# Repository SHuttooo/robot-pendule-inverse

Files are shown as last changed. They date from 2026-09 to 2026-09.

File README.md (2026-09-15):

# Robot pendule inversé

*Inverted pendulum robot. The name stays in French: this project was made in France.*

**English** · [Français](README.fr.md)

**A two-wheel robot that balances on its own: first with a hand-tuned dual PID,
then with a neural network trained in simulation and running on the ESP32.**

<table>
<tr>
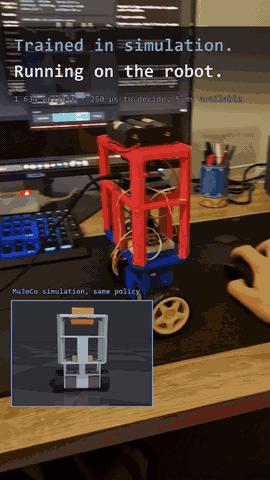
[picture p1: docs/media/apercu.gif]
The real robot pushed by hand, simulation in the corner
<td></td>
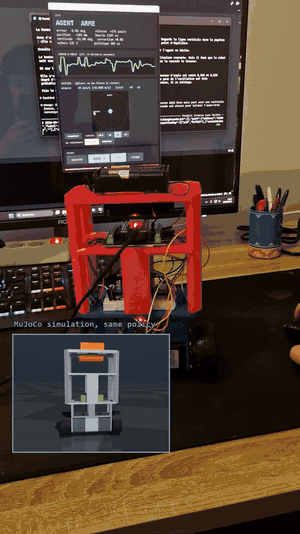
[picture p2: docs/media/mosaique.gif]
The 16 training checkpoints in simulation
<td></td>
</tr>
<tr>
<td align="center">real robot, same policy as in simulation</td>
<td align="center">16 training checkpoints, 9 M steps</td>
</tr>
</table>

Full video (45 s): see the [latest release](../../releases/latest).

> The code, its comments and the detailed documentation in the subfolders are
> in French. This page is the English entry point.

---

## Two ways to control the robot

The same firmware contains both, and you can switch between them live
(serial command `1` or `2`, or a button on the control panel).

| | **dual PID** (`1`) | **learned policy** (`2`) |
|---|---|---|
| origin | tuned by hand, to put my control engineering courses into practice | trained with PPO in MuJoCo |
| structure | 200 Hz angle loop → wheel acceleration, 40 Hz position loop that shifts the target angle, auto-trim of the upright angle | a 15 → 32 → 32 → 2 network, 1,634 weights, replacing both loops and deciding at 100 Hz |
| shared | IMU reading, speed integration, step generation, safety checks | same |

**In practice:** arm the dual PID for one minute first. Its auto-trim finds the
true upright angle, which the policy then reuses. The policy has no auto-trim.

The dual PID is also the **reference**: in simulation (`simulation/firmware.py`,
`08_agent.py --duel`) as on the robot, it tells whether a bad result comes from
the policy or from the hardware. On 9 September, run before the policy, it
balanced twelve times worse than earlier that evening: the problem was the
robot (discharged batteries: once recharged, everything worked again), not the
retraining.

---

## What's inside

```
hardware/     mechanics: SolidWorks CAD, STL, bill of materials, wiring, actual assembly
firmware/     ESP32 code: dual PID, learned policy, safety checks, serial commands
tools/        serial monitor (timestamped log) and control panel with joystick
simulation/   MuJoCo, Gymnasium environment, PPO, C export, videos
docs/         tuning notebook (as of 28 August), project log (pitfalls, decisions, results)
donnees/      raw serial logs from the robot, source of every measured number
```

| | |
|---|---|
| [`hardware/README.md`](hardware/README.md) | parts, assembly, **differences from the CAD** (IMU moved) |
| [`hardware/wiring.md`](hardware/wiring.md) | ESP32, A4988, MPU-6050 pinout, power supply |
| [`firmware/README.md`](firmware/README.md) | real-time architecture, commands, telemetry, flashing |
| [`simulation/README.md`](simulation/README.md) | the model, training, export to the ESP32 |
| [`simulation/modeles/balancier.xml`](simulation/modeles/balancier.xml) | **the robot model**, in MJCF (MuJoCo's XML format) |
| [`docs/journal/PIEGES.md`](docs/journal/PIEGES.md) | bugs met along the way, what they cost, the rule learned |
| [`docs/journal/RESULTATS.md`](docs/journal/RESULTATS.md) | every number, with the command that produces it |

---

## Results

**The simulation matches the real robot.** The same policy, evaluated in
simulation and on the hardware:

| | simulation | real robot |
|---|---|---|
| tilt error, standard deviation | 1.743° | 1.572° |
| motor command, standard deviation | 873 steps/s | 878 steps/s |

1% difference on the command, about 10% on the tilt. The simulation was never
fitted to this observation: only the motor resonance and the sensor noise were
calibrated, each measured separately.

**Retrained on this faithful model**, the new policy, in simulation:

| | old policy | **new policy** | dual PID |
|---|---|---|---|
| tilt error, standard deviation | 1.743° | **0.106°** | 0.185° |
| command, standard deviation | 873 steps/s | **47 steps/s** | 86 steps/s |
| position drift | 55 mm | 12 mm | 13 mm |
| survival at maximum difficulty | 25% | **42%** | 33% |

On the robot, the new policy balanced for 76 s with a command standard
deviation of 536 steps/s, versus 893 for the old one. **A measured comparison
against the dual PID on the hardware is still to be done.**

The hand-tuned dual PID had first brought the tilt error down from 0.293° to
0.064° (see the [notebook](docs/carnet-du-balancier.html), in French). Its purpose
was to put my control engineering courses into practice, not to build the best
possible controller.

**I deliberately skipped the full control engineering approach**: modelling the
pendulum, deriving its transfer function, finding its poles and designing a
controller properly. The gains were found by trial and measurement on the
robot, and I then moved straight on to reinforcement learning, which was the
real goal of the project.

---

## Getting started

**Simulation** (Python 3.12, from `simulation/`):

```
pip install -r requirements.txt
pip install torch --index-url https://download.pytorch.org/whl/cpu

python modele.py --etat                 every parameter and where it comes from
python 01_regarder.py                   the robot in the viewer
python 08_agent.py --agent agents/balancier_final.zip
python 08_agent.py --duel               policy against dual PID
python 07_ppo.py --actionneur couple --pas 9000000       retrain (~16 min)
python 11_export_c.py --agent agents/balancier_final.zip
python 12_valider_c.py                  the C code must match PyTorch
```

**Firmware**: open `firmware/robot_balancier/robot_balancier.ino` in the
Arduino IDE, board *ESP32 Dev Module*, esp32 core 3.3.

**Driving the robot** (Windows):

```
powershell -ExecutionPolicy Bypass -File tools\serial_monitor.ps1
python tools\pupitre.py
```

---

## Timeline

| | |
|---|---|
| **August 2026** | frame, electronics, dual PID tuned by hand through trial and measurement, without a full model. A quick calculation shows that commanding wheel speed cannot stabilise an inverted pendulum: switch to commanding acceleration. A bug in Espressif's I2C driver tracked down with `addr2line`. |
| **5 Sept** | MuJoCo model rebuilt from the SolidWorks assembly, firmware ported to simulation as a reference, first PPO policy. |
| **9 Sept** | policy exported to C and validated against PyTorch. Board crashes fixed by moving I2C to a dedicated task. Motor identified in closed loop with frequency sweeps and cross-spectra, without taking the robot apart: resonance at 71 Hz, not 113. Retraining on the faithful motor model. |
| **10 Sept** | steering (two independent wheel speeds from a single timer), joystick control panel, video. |

## Still open

- measure the dual PID and the policy on the hardware, under the same conditions;
- set the A4988 Vref, never measured;
- the period of the robot hanging as a pendulum, an independent check of the model ([`docs/MESURES.md`](docs/MESURES.md)).

---

**Matthieu Vinet**, robotics engineering student at Polytech Sorbonne ·
[matthieu-vinet.fr](https://matthieu-vinet.fr/)

Code written with Claude Code as a programming assistant. [MIT](LICENSE) license.

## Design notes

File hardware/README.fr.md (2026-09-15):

# Mécanique et matériel

[English](README.md) · **Français**

<table>
<tr>
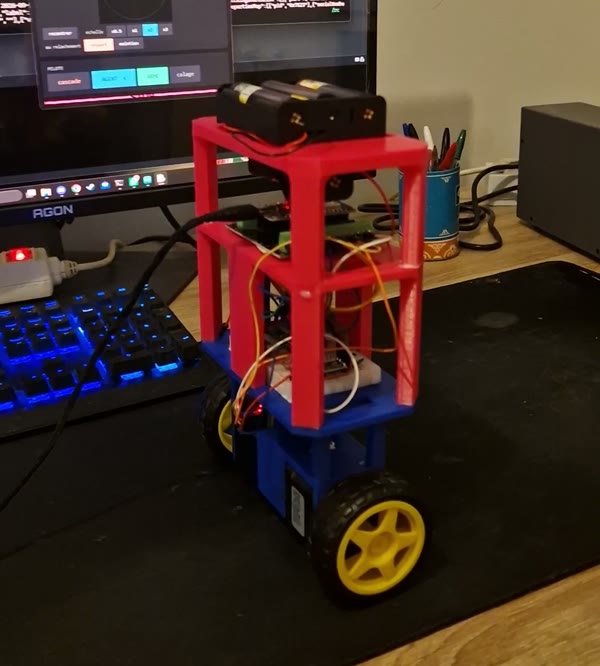
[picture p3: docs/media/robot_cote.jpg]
Le robot de côté
<td></td>
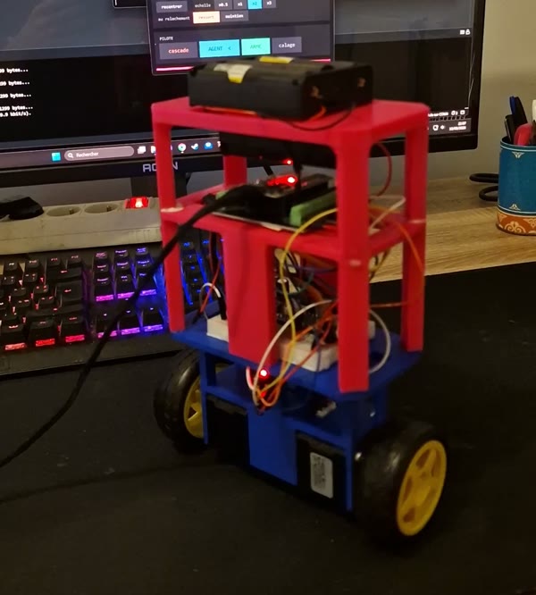
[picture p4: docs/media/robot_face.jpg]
Le robot de face
<td></td>
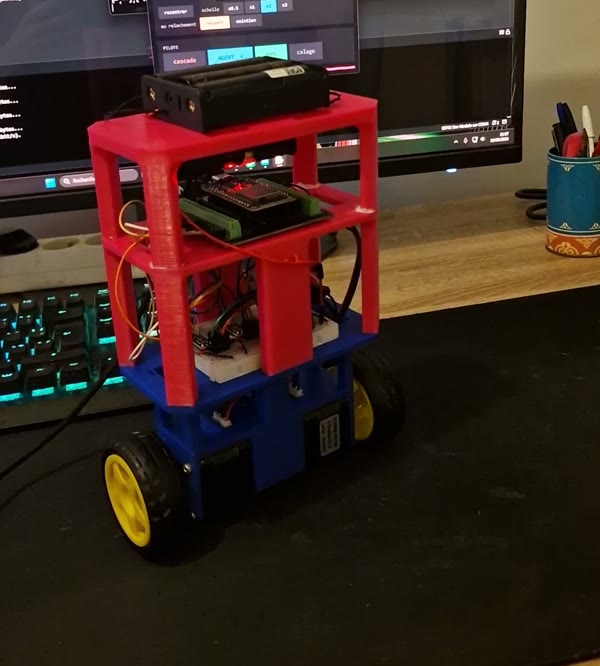
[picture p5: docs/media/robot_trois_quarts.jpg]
Le robot de trois quarts
<td></td>
</tr>
</table>

*Images extraites de la vidéo du 10 septembre 2026.*

Un pendule inversé sur deux roues. La pièce bleue du bas tient les deux
moteurs ; les trois étages rouges au-dessus portent la platine d'essai,
l'ESP32 et, tout en haut, le support des quatre batteries.

Le câblage est dans [`cablage.md`](cablage.md).

---

## Nomenclature

| composant | référence | qté | remarque |
|---|---|---|---|
| microcontrôleur | ESP32 WROOM-32D, carte de développement | 1 | |
| centrale inertielle | MPU-6050 | 1 | I2C, adresse 0x68 |
| drivers moteur | A4988 | 2 | micropas 1/8, soit 1 600 pas/tour (mesuré) |
| moteurs | NEMA 17 17HS3401S | 2 | |
| batteries | 18650 Li-ion 3,7 V LiitoKala | 4 | en série : 4S, 14,8 V nominal |
| convertisseur | abaisseur vers 5 V | 1 | alimente l'ESP32 par sa broche VIN |
| condensateur | 100 µF | 1 | sur VMOT |
| platine d'essai | breadboard | 1 | |
| roues | Ø 65 mm, 26 mm de large | 2 | |
| pièces imprimées | `piece1` à `piece4` | 4 | voir ci-dessous |
| inserts filetés | M2.5 | 2 | prévus pour l'emplacement d'origine de l'IMU, finalement pas utilisés |
| scotch double face | | | fixe l'ESP32, la platine, les batteries et l'IMU |

---

## Les pièces

| pièce | encombrement | volume imprimé |
|---|---|---|
| `piece1` | 113 × 42 × 47 mm | 92,8 cm³ |
| `piece2` | 143 × 75 × 45 mm | 65,2 cm³ |
| `piece3` | 143,6 × 75,6 × 80 mm | 118,1 cm³ |
| `piece4` | 143,7 × 75,7 × 63 mm | 103,5 cm³ |

Robot assemblé : 143,7 × 75,7 × 220 mm, 231,5 mm de haut roues comprises.
Étagères à +66, +141 et +199 mm au-dessus de l'axe des roues. Toutes ces cotes
sont lues dans l'assemblage par `simulation/modele.py`, pas mesurées au pied à
coulisse.

### Les fichiers

| dossier | contenu |
|---|---|
| `cao/solidworks/` | `Assemblage1.SLDASM` et les 5 pièces. **Version du 25 août 2026, la dernière.** |
| `cao/stl/` | les 4 pièces à imprimer. `piece2` à `piece4` sont les exports du 25 août (les anciens `v2`). |
| `cao/stl_assemblage/` | les 6 STL exportés dans le repère de l'assemblage, lus par la simulation |

### La retouche du 25 août

Comparaison des maillages avant et après : l'enveloppe extérieure des pièces
ne bouge pas. Un seul contour change, sur 5 mm de haut, en haut de chaque pièce.

| pièce | avant | après | par côté |
|---|---|---|---|
| `piece2` (tenon) | 107,90 × 36,90 mm | 107,70 × 36,70 mm | −0,10 mm |
| `piece3` | 130,74 × 66,90 mm | 130,46 × 66,70 mm | −0,14 / −0,10 mm |
| `piece4` | 130,73 × 62,73 mm | 130,45 × 62,45 mm | −0,14 mm |

C'est du jeu ajouté pour l'emboîtement des étages.

Les STL de `cao/stl_assemblage/` ont été exportés **avant** cette retouche
(vérifié par la géométrie : 0,01 mm d'écart avec l'ancienne `piece2`, 0,11 mm
avec la nouvelle). Sur la masse et l'inertie du modèle, 0,1 mm de paroi ne se
voit pas. Pour les aligner malgré tout : réexporter l'assemblage en STL, une
pièce par fichier, dans le repère de l'assemblage.

---

## Le montage réel diffère de la CAO

### L'IMU a été déplacée loin des moteurs

L'assemblage SolidWorks montre l'emplacement **prévu** de l'IMU, pas celui du
robot :

| | pièce | endroit | fixation |
|---|---|---|---|
| **prévu dans la CAO** | `piece1`, la pièce du bas | celle qui tient les deux moteurs | 2 inserts filetés M2.5 |
| **sur le robot** | `piece2`, la deuxième en partant du bas | sur le côté du pied central qui la porte | scotch double face |

Pourquoi : un moteur pas-à-pas avance par à-coups, 1 600 fois par tour. Collée
près de lui, l'IMU mesure ces vibrations en plus du mouvement du robot, et le
gyroscope les prend pour des rotations. Le terme dérivé du régulateur les
amplifie ensuite. Au début de la mise au point, le carnet relevait 3,48 °/s de
bruit sur le gyroscope.

Les deux **inserts M2.5** prévus pour la fixer sur la pièce des moteurs n'ont
donc finalement pas servi. Si on réimprime `piece1`, leurs logements peuvent
être ignorés.

**Orientation, à respecter si on la déplace encore.** Le firmware ne lit que
`AY`, `AZ` et `GX` : l'axe X du capteur doit rester parallèle à l'axe des roues.
Le capteur est monté couché, d'où une verticale lue vers −91,4° et non 0°. La
commande `Z` recale ce zéro, robot tenu droit.

### Fixations au scotch double face

L'**ESP32**, la **platine d'essai**, les **batteries** et l'**IMU** sont collés
au scotch double face, sans vis.

Deux conséquences :

- une pièce collée peut glisser après une chute. Si l'IMU a bougé, le point
  d'équilibre bouge avec elle : refaire le calage (`Z`) puis laisser le double
  PID tourner une minute pour que l'auto-trim retrouve la verticale ;
- pour l'IMU, un double face **épais, en mousse**, filtre en plus une partie des
  vibrations des moteurs.

---

## Points de vigilance

| | |
|---|---|
| **Vref des A4988** | jamais réglé. Il fixe le couple disponible. Procédure : `Vref = I × 8 × Rshunt`, voir le [carnet](../docs/carnet-du-balancier.html). |
| **ENABLE** | non câblé : les moteurs restent alimentés et chauffent même à l'arrêt. |
| **Charge des batteries** | le robot ne la mesure pas. Des batteries déchargées dégradent l'équilibre bien avant la chute (douze fois pire le 9 septembre 2026) : les charger avant toute mesure. |
| **USB et 5 V** | ne jamais alimenter l'ESP32 par l'USB et par le convertisseur en même temps. Garder les masses communes, débrancher le fil 5 V. |
| **Historique** | un premier ESP32 a été détruit par du 12 V sur sa broche 3V3. Les drivers et l'IMU ont été changés, pas le convertisseur. |

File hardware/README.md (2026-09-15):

# Mechanics and hardware

**English** · [Français](README.fr.md)

<table>
<tr>
<td>The robot from the side</td>
<td>The robot from the front</td>
<td>The robot, three-quarter view</td>
</tr>
</table>

*Frames taken from the video of 10 September 2026.*

An inverted pendulum on two wheels. The blue bottom part holds both motors; the
three red levels above carry the breadboard, the ESP32 and, at the very top,
the holder for the four batteries.

Wiring is described in [`wiring.md`](wiring.md).

---

## Bill of materials

| component | part | qty | note |
|---|---|---|---|
| microcontroller | ESP32 WROOM-32D, development board | 1 | |
| IMU | MPU-6050 | 1 | I2C, address 0x68 |
| motor drivers | A4988 | 2 | 1/8 microstepping, i.e. 1,600 steps/rev (measured) |
| motors | NEMA 17 17HS3401S | 2 | |
| batteries | 18650 Li-ion 3.7 V LiitoKala | 4 | in series: 4S, 14.8 V nominal |
| converter | step-down to 5 V | 1 | powers the ESP32 through its VIN pin |
| capacitor | 100 µF | 1 | on VMOT |
| breadboard | | 1 | |
| wheels | Ø 65 mm, 26 mm wide | 2 | |
| printed parts | `piece1` to `piece4` | 4 | see below |
| threaded inserts | M2.5 | 2 | planned for the original IMU location, never used in the end |
| double-sided tape | | | holds the ESP32, breadboard, batteries and IMU |

---

## The parts

| part | bounding box | printed volume |
|---|---|---|
| `piece1` | 113 × 42 × 47 mm | 92.8 cm³ |
| `piece2` | 143 × 75 × 45 mm | 65.2 cm³ |
| `piece3` | 143.6 × 75.6 × 80 mm | 118.1 cm³ |
| `piece4` | 143.7 × 75.7 × 63 mm | 103.5 cm³ |

Assembled robot: 143.7 × 75.7 × 220 mm, 231.5 mm tall including wheels. Shelves
at +66, +141 and +199 mm above the wheel axle. All these dimensions are read
from the assembly by `simulation/modele.py`, not measured with calipers.

### Files

| folder | content |
|---|---|
| `cao/solidworks/` | `Assemblage1.SLDASM` and its 5 parts. **Version of 25 August 2026, the latest.** |
| `cao/stl/` | the 4 parts to print. `piece2` to `piece4` are the 25 August exports (formerly `v2`). |
| `cao/stl_assemblage/` | the 6 STL files exported in the assembly frame, loaded by the simulation |

### The 25 August revision

Comparing the meshes before and after: the outer shape of the parts does not
change. A single contour changes, 5 mm high, at the top of each part.

| part | before | after | per side |
|---|---|---|---|
| `piece2` (tenon) | 107.90 × 36.90 mm | 107.70 × 36.70 mm | −0.10 mm |
| `piece3` | 130.74 × 66.90 mm | 130.46 × 66.70 mm | −0.14 / −0.10 mm |
| `piece4` | 130.73 × 62.73 mm | 130.45 × 62.45 mm | −0.14 mm |

This is clearance added so the levels fit into each other.

The STL files in `cao/stl_assemblage/` were exported **before** this revision
(checked on the geometry: 0.01 mm from the old `piece2`, 0.11 mm from the new
one). A 0.1 mm wall change has no visible effect on the model's mass and
inertia. To align them anyway: re-export the assembly as STL, one file per part,
in the assembly frame.

---

## The actual robot differs from the CAD

### The IMU was moved away from the motors

The SolidWorks assembly shows the **planned** IMU location, not the one on the
robot:

| | part | location | mounting |
|---|---|---|---|
| **planned in the CAD** | `piece1`, the bottom part | the one holding both motors | 2 M2.5 threaded inserts |
| **on the robot** | `piece2`, second from the bottom | on the side of the central leg that supports it | double-sided tape |

Why: a stepper motor moves in small jerks, 1,600 per revolution. Mounted close
to it, the IMU picks up these vibrations on top of the robot's motion, and the
gyroscope reads them as rotations. The controller's derivative term then
amplifies them. At the start of tuning, the notebook recorded 3.48 °/s of
gyroscope noise.

The two **M2.5 inserts** planned to hold it on the motor part were therefore
never used. If `piece1` is printed again, their holes can be ignored.

**Orientation, to keep if it is moved again.** The firmware only reads `AY`,
`AZ` and `GX`: the sensor's X axis must stay parallel to the wheel axle. The
sensor is mounted on its side, so upright reads around −91.4° instead of 0°.
The `Z` command resets that zero while the robot is held upright.

### Mounting with double-sided tape

The **ESP32**, the **breadboard**, the **batteries** and the **IMU** are stuck
on with double-sided tape, no screws.

Two consequences:

- a taped part can slip after a fall. If the IMU moved, the balance point moves
  with it: redo the zero (`Z`), then let the dual PID run for a minute so the
  auto-trim finds upright again;
- for the IMU, **thick foam** double-sided tape also filters part of the motor
  vibrations.

---

## Things to watch

| | |
|---|---|
| **A4988 Vref** | never set. It sets the available torque. Procedure: `Vref = I × 8 × Rshunt`, see the [notebook](../docs/carnet-du-balancier.html) (in French). |
| **ENABLE** | not wired: the motors stay powered and heat up even when idle. |
| **Battery charge** | the robot does not measure it. Discharged batteries degrade balancing long before the robot falls (twelve times worse on 9 September 2026): charge them before any measurement. |
| **USB and 5 V** | never power the ESP32 from USB and from the converter at the same time. Keep the grounds common, disconnect the 5 V wire. |
| **History** | a first ESP32 was destroyed by 12 V on its 3V3 pin. The drivers and the IMU were replaced, the converter was not. |

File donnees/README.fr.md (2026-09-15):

# Données brutes du robot

[English](README.md) · **Français**

`logs_robot_2026-08-28_au_2026-09-12.zip` (3,7 Mo compressés, 31 Mo bruts) :
tout le port série du robot, horodaté à la milliseconde par
`tools/serial_monitor.ps1`. C'est la source de chaque chiffre mesuré sur le
matériel dans ce dépôt.

| fichier | période | contenu |
|---|---|---|
| `robot-avant.log` | jusqu'au 28 août | la mise au point du double PID (carnet) |
| `robot.log.old` | jusqu'au 10 sept, 19 h 12 | crash I2C, identification du moteur, premier vol de l'agent |
| `robot.log` | 10 au 12 sept | direction, pupitre, la prise vidéo du 10 sept à 21 h 06 |

**Piège :** le journal pivote à 20 Mo. Tout le 9 septembre est donc dans
`robot.log.old`, et une analyse faite sur `robot.log` seul donne des chiffres
faux. C'est arrivé.

Pour s'en servir : décompresser dans `logs/` à la racine du dépôt (le dossier
est ignoré par git).

## Lire une ligne de télémétrie

```
10:53:31.710 P:-90.06 tgt:-90.46 e:0.40 g:6.2 PID DUAL sps:-19 c:-0.62 off:-91.08 pos:-165 hz:199 f:0 Lus:1225 Ius:1170 Tp:0 Tr:0
```

Le détail de chaque champ est dans [`firmware/README.fr.md`](../firmware/README.fr.md#télémétrie).

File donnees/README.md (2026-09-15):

# Raw robot data

**English** · [Français](README.fr.md)

`logs_robot_2026-08-28_au_2026-09-12.zip` (3.7 MB compressed, 31 MB raw):
everything that went through the robot's serial port, timestamped to the
millisecond by `tools/serial_monitor.ps1`. It is the source of every number
measured on the hardware in this repository.

| file | period | content |
|---|---|---|
| `robot-avant.log` | up to 28 August | tuning of the dual PID (notebook) |
| `robot.log.old` | up to 10 Sept, 19:12 | I2C crash, motor identification, first policy run |
| `robot.log` | 10 to 12 Sept | steering, control panel, the video take of 10 Sept at 21:06 |

**Pitfall:** the log rotates at 20 MB. All of 9 September is therefore in
`robot.log.old`, and an analysis run on `robot.log` alone gives wrong numbers.
It happened.

To use it: unzip into `logs/` at the repository root (the folder is ignored by
git).

## Reading a telemetry line

```
10:53:31.710 P:-90.06 tgt:-90.46 e:0.40 g:6.2 PID DUAL sps:-19 c:-0.62 off:-91.08 pos:-165 hz:199 f:0 Lus:1225 Ius:1170 Tp:0 Tr:0
```

Every field is described in [`firmware/README.md`](../firmware/README.md#telemetry).

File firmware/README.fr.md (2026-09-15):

# Firmware ESP32

[English](README.md) · **Français**

Un seul croquis Arduino, `robot_balancier/robot_balancier.ino`, et l'en-tête
généré `robot_balancier/politique.h`.

| | |
|---|---|
| carte | ESP32 Dev Module (`esp32:esp32:esp32`) |
| core | esp32 d'Espressif 3.3 (compatible 2.x par les macros `TIMER_*`) |
| taille | 364 ko de flash (27 %), 71 ko de RAM (21 %) |
| bibliothèques | aucune hors du core : `Wire`, `Preferences` |

```
arduino-cli compile --fqbn esp32:esp32:esp32 robot_balancier
```

**Avant de téléverser :** vider `tools/cmd.txt` (une commande oubliée part au
redémarrage), et poser le robot : le téléversement coupe la carte huit
secondes.

---

## Deux pilotes pour le même robot

**Le double PID** (commande `1`), réglé à la main pour mettre en pratique mes
cours d'automatique. Les gains viennent d'essais et de mesures sur le robot,
pas d'une modélisation du pendule avec placement de pôles : j'ai sauté cette
étape pour passer directement à l'apprentissage par renforcement.

```
boucle interne, 200 Hz, cadencée par l'INT du MPU-6050
    accélération roue = Kp·erreur + Ki·∫erreur + Kd·gyro      [pas/s²]
    vitesse roue     += accélération · dt                      l'intégrateur EST la commande
boucle externe, 40 Hz
    angle cible = offset − (Kp_v·erreur de vitesse + Ki_v·erreur de position)
auto-trim, très lent
    recale l'offset pour que la correction externe tende vers zéro
```

Pour un pendule inversé, c'est l'accélération du point d'appui qui redresse le
corps. Une vitesse proportionnelle à l'angle garde toujours un pôle réel
positif, quels que soient les gains : c'était la première version, et elle ne
pouvait pas marcher.

**L'agent** (commande `2`) : `politique.h`, un réseau 15 → 32 → 32 → 2 en tanh,
1 634 poids en flash. Il décide à 100 Hz et remplace **les deux boucles** : il
a déjà l'écart de position et la consigne de vitesse dans ses entrées.
L'intégrateur de vitesse, les limites et les sécurités restent en place.

> **L'auto-trim ne tourne pas en mode agent.** Il vit dans la boucle externe,
> désactivée quand l'agent pilote. Armer le double PID **une minute avant** de
> passer à l'agent, pour que l'offset corresponde à la vraie verticale.

Le mode d'emploi complet de l'intégration, et le protocole de vérification du
signe, sont dans [`INTEGRATION.md`](INTEGRATION.md). Pour régénérer l'en-tête
après un réentraînement : `simulation/11_export_c.py` puis
`simulation/12_valider_c.py`, **jamais l'un sans l'autre**.

---

## Architecture temps réel

**Lecture de l'IMU dans une tâche dédiée**, sur le cœur 0. Réveillée par l'INT
du MPU-6050, elle lit 8 octets à partir du registre 0x3D (AY, AZ, TEMP, GX) et
publie l'échantillon sous verrou. Quand la transaction I2C vivait dans
`loop()`, un bus figé bloquait la boucle de commande et le chien de garde
redémarrait la carte : deux plantages en 106 s de secousse. Après : 252 s sans
un seul, et 0 échec I2C au repos contre 1 par seconde.

**Génération des pas.** Un timer bat à 25 kHz. Chaque roue a son accumulateur
en virgule fixe 16.16 ; quand il déborde, cette roue fait un pas (algorithme de
Bresenham). Deux vitesses indépendantes sur un seul timer, donc la direction.

**Sécurités**, de la plus rapide à la plus lente :

| | |
|---|---|
| homme mort dans l'ISR | 1 250 tops (50 ms) sans nouvelle consigne : les pas s'arrêtent |
| IMU muette 40 ms | la commande est coupée |
| IMU muette 150 ms | désarmement, `>>> SECURITE : bus I2C fige` |
| IMU muette 3 s | redémarrage de la carte |
| inclinaison > 30° | coupure |
| chien de garde | redémarrage si `loop()` se bloque |
| boîte noire | l'étape en cours est écrite en RAM RTC, qui survit au redémarrage : après un plantage, le démarrage dit **où** la boucle s'est arrêtée |

---

## Commandes série

115 200 bauds. Une lettre, éventuellement suivie d'une valeur (`N400`).

**Piloter**

| cmd | effet |
|---|---|
| `1` | pilote = double PID |
| `2` | pilote = agent |
| `K` | arme la double boucle, angle et position |
| `G` | angle seul (le robot dérive, c'est normal) |
| `S` | **arrêt**, annule aussi un armement en attente |
| `Z` | calage : l'angle courant devient la verticale |
| `N`*sps* | consigne de vitesse en pas/s |
| `#`*sps* | différence de vitesse entre les roues, positif = virage à droite, ±2 000 |
| `W`*s* | durée d'un trajet `N` ; non nulle, le robot fait l'aller puis le retour |

**Tester et mesurer**

| cmd | effet |
|---|---|
| `3` | test de signe de la politique, **roues en l'air**, moteurs muets |
| `4` | secousse : inversions pleine amplitude à 5 Hz, sans IMU ni asservissement |
| `5` | rampe de décrochage moteur, **roues en l'air** |
| `6` | enregistrement 200 Hz pendant 6 s, vidé en CSV (`ENR`) sans désarmer |
| `7` | balayage de 0,5 à 20 Hz en 5 s, injecté sur l'accélération. Le robot vibre sur place. Double PID armé d'abord (`1` puis `K`). |
| `9` | balayage de 0,2 à 3 Hz en 5,5 s sur la consigne d'angle, amplitude 1°. Le robot se dandine sur environ 2 cm. |
| `0` | avance d'environ 10 cm après 1 s de repos, enregistrée, puis revient seul. Double PID armé d'abord. |
| `8` | affiche un message d'un ancien protocole de poussée, sans effet |
| `C` | relance la calibration du gyroscope |
| `V`*rpm* | mode manuel avec rampe, roues en l'air |

**Régler** (sauvegardé en flash)

| cmd | paramètre |
|---|---|
| `P` `I` `D` | gains de la boucle interne |
| `T` `Y` | gains vitesse et position de la boucle externe |
| `O` | offset d'angle |
| `L` | constante de temps du lissage de vitesse |
| `U` `E` | coup de pouce au démarrage, avance max de la cible |
| `M` `R` `B` | vitesse max, accélération max, accélération du mode manuel |
| `A` `H` `J` `X` | bascules : auto-trim, réarmement auto, armement au démarrage, signe de la boucle externe |
| `F` `Q` `?` | forcer la sauvegarde, effacer la flash, afficher tous les paramètres |

---

## Télémétrie

Une ligne toutes les 100 ms :

```
P:-90.06 tgt:-90.46 e:0.40 g:6.2 PID DUAL sps:-19 c:-0.62 off:-91.08 pos:-165 hz:199 f:0 Lus:1225 Ius:1170 Tp:0 Tr:0
```

| champ | sens | repère |
|---|---|---|
| `P` | angle mesuré, degrés | verticale vers −91° (IMU couchée) |
| `tgt` | angle cible | |
| `e` | erreur d'angle | |
| `g` | vitesse gyroscopique filtrée, °/s | ≈ 0 au repos |
| `PID` / `AGENT` | pilote actif | |
| `DUAL` / `ANG` / `OFF` | double boucle, angle seul, désarmé | |
| `sps` | commande de vitesse roue, pas/s | saturée = chute imminente |
| `c` | correction de la boucle externe, degrés | > 1° durablement = offset faux |
| `off` | offset d'angle | stable au repos |
| `pos` | odométrie, en pas commandés | |
| `hz` | fréquence de boucle | 200 |
| `f` | échecs I2C cumulés | 0 |
| `Lus` | pire itération de boucle, µs | < 3 000 |
| `Ius` | pire transaction I2C, µs | < 1 500 |
| `Pus` | pire inférence de la politique, µs (mode agent) | |
| `Tp` `Tr` | reprogrammations et rallumages du timer | 0 depuis le timer à cadence fixe |
| `BLOC` | présent seulement si le bus I2C est bloqué | |

---

## Les outils, dans `tools/`

Un seul programme tient le port série : **`serial_monitor.ps1`**. Il détecte la
carte, écrit tout dans `logs/robot.log` horodaté à la milliseconde, envoie ce
qu'on dépose dans `tools/cmd.txt`, et libère le port tout seul pendant un
téléversement. Le fichier `tools/PAUSE` libère le port, `tools/STOP` arrête le
moniteur. Il ne survit pas toujours au téléversement : vérifier qu'il tourne
avant de conclure quoi que ce soit d'un journal muet.

**`pupitre.py`** : joystick 2D pour la vitesse et la direction, échelles de
×0,5 à ×3, calage, choix du pilote, STOP (touche Échap). Il ne touche jamais le
port : il lit le journal et écrit dans `cmd.txt`. Ses boutons s'allument
d'après la télémétrie, pas d'après le dernier clic, donc un ordre perdu se voit.

```
powershell -ExecutionPolicy Bypass -File tools\serial_monitor.ps1
python tools\pupitre.py
```

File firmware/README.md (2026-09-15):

# ESP32 firmware

**English** · [Français](README.fr.md)

A single Arduino sketch, `robot_balancier/robot_balancier.ino`, and the
generated header `robot_balancier/politique.h`. Code comments are in French.

| | |
|---|---|
| board | ESP32 Dev Module (`esp32:esp32:esp32`) |
| core | Espressif esp32 3.3 (2.x compatible through the `TIMER_*` macros) |
| size | 364 kB flash (27%), 71 kB RAM (21%) |
| libraries | nothing outside the core: `Wire`, `Preferences` |

```
arduino-cli compile --fqbn esp32:esp32:esp32 robot_balancier
```

**Before flashing:** empty `tools/cmd.txt` (a leftover command is sent on
reboot), and put the robot down: flashing cuts power to the board for eight
seconds.

---

## Two controllers for the same robot

**The dual PID** (command `1`), tuned by hand to put my control engineering
courses into practice. The gains come from trials and measurements on the
robot, not from a pendulum model with pole placement: I skipped that step to go
straight to reinforcement learning.

```
inner loop, 200 Hz, clocked by the MPU-6050 INT pin
    wheel acceleration = Kp·error + Ki·∫error + Kd·gyro      [steps/s²]
    wheel speed       += acceleration · dt                   the integrator IS the command
outer loop, 40 Hz
    target angle = offset − (Kp_v·speed error + Ki_v·position error)
auto-trim, very slow
    shifts the offset so the outer correction tends to zero
```

For an inverted pendulum, it is the acceleration of the contact point that
rights the body. A wheel speed proportional to the angle always leaves a
positive real pole, whatever the gains: that was the first version, and it could
not work.

**The policy** (command `2`): `politique.h`, a 15 → 32 → 32 → 2 tanh network,
1,634 weights in flash. It decides at 100 Hz and replaces **both loops**: its
inputs already include the position error and the speed setpoint. The speed
integrator, the limits and the safety checks stay in place.

> **The auto-trim does not run in policy mode.** It lives in the outer loop,
> which is disabled while the policy drives. Arm the dual PID **one minute
> before** switching to the policy, so the offset matches the true upright.

The full integration guide and the sign check procedure are in
[`INTEGRATION.md`](INTEGRATION.md) (in French). To regenerate the header after
retraining: `simulation/11_export_c.py` then `simulation/12_valider_c.py`,
**never one without the other**.

---

## Real-time architecture

**IMU reading in a dedicated task**, on core 0. Woken by the MPU-6050 INT pin,
it reads 8 bytes from register 0x3D (AY, AZ, TEMP, GX) and publishes the sample
under a lock. When the I2C transaction lived in `loop()`, a stuck bus blocked
the control loop and the watchdog rebooted the board: two crashes in 106 s of
shaking. After: 252 s without a single one, and 0 I2C failures at rest versus 1
per second.

**Step generation.** A timer ticks at 25 kHz. Each wheel has its own 16.16
fixed-point accumulator; when it overflows, that wheel takes a step
(Bresenham's algorithm). Two independent speeds from a single timer, hence
steering.

**Safety checks**, fastest first:

| | |
|---|---|
| dead man's switch in the ISR | 1,250 ticks (50 ms) without a new command: stepping stops |
| IMU silent 40 ms | command cut |
| IMU silent 150 ms | disarm, `>>> SECURITE : bus I2C fige` |
| IMU silent 3 s | board reboot |
| tilt > 30° | cut |
| watchdog | reboot if `loop()` hangs |
| black box | the current stage is written to RTC RAM, which survives a reboot: after a crash, the boot message says **where** the loop stopped |

---

## Serial commands

115,200 baud. One letter, optionally followed by a value (`N400`).

**Driving**

| cmd | effect |
|---|---|
| `1` | controller = dual PID |
| `2` | controller = policy |
| `K` | arm both loops, angle and position |
| `G` | angle loop only (the robot drifts, that is expected) |
| `S` | **stop**, also cancels a pending arm |
| `Z` | zero: the current angle becomes upright |
| `N`*sps* | speed setpoint in steps/s |
| `#`*sps* | speed difference between wheels, positive = turn right, ±2,000 |
| `W`*s* | duration of an `N` move; when non-zero, the robot goes out and back |

**Testing and measuring**

| cmd | effect |
|---|---|
| `3` | policy sign check, **wheels in the air**, motors silent |
| `4` | shake: full-amplitude reversals at 5 Hz, without IMU or feedback |
| `5` | motor stall ramp, **wheels in the air** |
| `6` | 200 Hz recording for 6 s, dumped as CSV (`ENR`) without disarming |
| `7` | 0.5 to 20 Hz sweep over 5 s, injected on acceleration. The robot vibrates in place. Arm the dual PID first (`1` then `K`). |
| `9` | 0.2 to 3 Hz sweep over 5.5 s on the angle setpoint, 1° amplitude. The robot rocks over about 2 cm. |
| `0` | moves about 10 cm forward after 1 s at rest, recorded, then comes back on its own. Arm the dual PID first. |
| `8` | prints a message from an old push protocol, no effect |
| `C` | restart gyroscope calibration |
| `V`*rpm* | manual mode with ramp, wheels in the air |

**Tuning** (saved to flash)

| cmd | parameter |
|---|---|
| `P` `I` `D` | inner loop gains |
| `T` `Y` | outer loop speed and position gains |
| `O` | angle offset |
| `L` | time constant of the speed filter |
| `U` `E` | start boost, maximum lead of the target |
| `M` `R` `B` | max speed, max acceleration, manual mode acceleration |
| `A` `H` `J` `X` | toggles: auto-trim, auto re-arm, arm at boot, outer loop sign |
| `F` `Q` `?` | force save, erase flash, print all parameters |

---

## Telemetry

One line every 100 ms:

```
P:-90.06 tgt:-90.46 e:0.40 g:6.2 PID DUAL sps:-19 c:-0.62 off:-91.08 pos:-165 hz:199 f:0 Lus:1225 Ius:1170 Tp:0 Tr:0
```

| field | meaning | expected |
|---|---|---|
| `P` | measured angle, degrees | upright around −91° (IMU on its side) |
| `tgt` | target angle | |
| `e` | angle error | |
| `g` | filtered gyro rate, °/s | ≈ 0 at rest |
| `PID` / `AGENT` | active controller | |
| `DUAL` / `ANG` / `OFF` | both loops, angle only, disarmed | |
| `sps` | wheel speed command, steps/s | saturated = fall imminent |
| `c` | outer loop correction, degrees | > 1° for long = wrong offset |
| `off` | angle offset | stable at rest |
| `pos` | odometry, in commanded steps | |
| `hz` | loop rate | 200 |
| `f` | cumulative I2C failures | 0 |
| `Lus` | worst loop iteration, µs | < 3,000 |
| `Ius` | worst I2C transaction, µs | < 1,500 |
| `Pus` | worst policy inference, µs (policy mode) | |
| `Tp` `Tr` | timer reprogrammings and restarts | 0 since the fixed-rate timer |
| `BLOC` | shown only if the I2C bus is stuck | |

---

## Tools, in `tools/`

A single program owns the serial port: **`serial_monitor.ps1`**. It finds the
board, writes everything to `logs/robot.log` with millisecond timestamps, sends
whatever is dropped into `tools/cmd.txt`, and releases the port by itself during
flashing. Creating `tools/PAUSE` releases the port, `tools/STOP` stops the
monitor. It does not always survive flashing: check it is running before
drawing conclusions from a silent log.

**`pupitre.py`** (control panel): 2D joystick for speed and steering, scale from
×0.5 to ×3, zeroing, controller selection, STOP (Escape key). It never touches
the port: it reads the log and writes to `cmd.txt`. Its buttons light up from
the telemetry, not from the last click, so a lost command is visible.

```
powershell -ExecutionPolicy Bypass -File tools\serial_monitor.ps1
python tools\pupitre.py
```

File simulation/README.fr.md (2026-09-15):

# Simulation et apprentissage

[English](README.md) · **Français**

Le robot reconstruit dans MuJoCo depuis son assemblage SolidWorks, le double PID
du firmware porté tel quel comme témoin, et un agent PPO entraîné pour le
battre puis exporté en C vers l'ESP32.

**Tous les scripts se lancent depuis ce dossier.**

```
pip install -r requirements.txt
pip install torch --index-url https://download.pytorch.org/whl/cpu
```

---

## Le modèle du robot

**`modeles/balancier.xml`** : le robot au format MJCF, le XML de MuJoCo. Il est
généré par `modele.py`, jamais édité à la main, et charge les maillages depuis
`hardware/cao/stl_assemblage/`. Ce fichier utilise l'actionneur en vitesse de
MuJoCo ; le modèle fidèle du moteur pas-à-pas, celui de l'entraînement, est
ajouté par `modele.xml('couple')` et `moteur.py`.

Il n'y a pas d'URDF : rien dans ce projet n'utilise ROS.

## Le principe

Un agent entraîné sur un modèle faux apprend à équilibrer un robot qui
n'existe pas, et on ne s'en aperçoit qu'au transfert. Le modèle est donc validé
**avant** d'entraîner, et chaque valeur porte sa provenance :

```
python modele.py --etat
```

`MESURE` (sur le robot, une fiche technique ou l'assemblage), `DEDUIT`
(calculé depuis une mesure), `ESTIME`, `SUPPOSE`. Il reste 2 paramètres non
établis sur 24.

La géométrie n'est pas saisie : les 6 STL de `hardware/cao/stl_assemblage/`
portent la masse, et MuJoCo calcule les inerties sur la vraie forme.

## Le moteur, la pièce qui a tout changé

Un moteur pas-à-pas n'est pas une source de vitesse. C'est un **ressort
magnétique** entre la position commandée et la position du rotor :

```
C = C_maintien · sin(50 · (θ_commande − θ_rotor))
```

Ce ressort résonne. La résonance a été **mesurée à 71 Hz** sur le robot, pas les
113 Hz supposés au départ, par des balayages fréquentiels injectés en boucle
fermée et des interspectres, sans démonter le robot. Avec l'actionneur
`<velocity>` de MuJoCo, l'ancien agent paraissait parfait. Sur le robot, il
tremblait dix fois plus. Avec `moteur.py`, la simulation reproduit ce
tremblement à 1 % près sur la commande, sans avoir été recalée dessus.

---

## Les scripts, dans l'ordre du parcours

| | |
|---|---|
| `modele.py` | génère le MJCF, tient la provenance de chaque chiffre |
| `moteur.py` | le pas-à-pas fidèle : ressort magnétique, décrochage |
| `etat.py` | lit l'état **par les capteurs simulés**, jamais par `qpos` |
| `firmware.py` | le double PID du `.ino` transcrit en Python |
| `balancier_env.py` | l'environnement Gymnasium : 15 observations, 2 actions, curriculum |
| `01_regarder.py` | le viewer (`--pousser`, `--mesh`) |
| `02_identifier.py` | le mode propre du modèle, confronté au carnet |
| `03_pid.py` | le double PID du firmware en simulation (`--vue`, `--silence`) |
| `04_pousser.py` | la poussée maximale encaissée (`--balayage`) |
| `05_bac_a_sable.py` | pousser le robot à la souris |
| `06_env.py` | vérification de l'environnement (`--cascade`) |
| `07_ppo.py` | l'entraînement |
| `08_agent.py` | regarder un agent (`--duel` contre le double PID, `--film`) |
| `09_piloter.py` | piloter en simulation avec un pupitre |
| `10_limites.py` | jusqu'où chacun tient |
| `11_export_c.py` | exporte la politique en C, **directement dans** `firmware/robot_balancier/politique.h` |
| `12_valider_c.py` | compile l'en-tête avec gcc et le compare à PyTorch |
| `15_moteur_identique.py` | vérifie que la copie rapide du moteur dans `balancier_env.py` donne exactement le couple de `moteur.py` |
| `17_pousser_agents.py` | la poussée maximale de chaque pilote, sur le moteur fidèle |
| `incertitude.py` `moteur_duel.py` `bench_rl.py` | propagation d'incertitude, vitesse contre couple, débit PPO |
| `film.py` `rendu.py` | les vidéos de simulation |
| `montage_reel.py` `montage_duo.py` `19_mosaique_verticale.py` `montage_post.py` | le montage de la vidéo publiée |

Après toute modification de `modele.py` : `python modele.py` pour régénérer
`modeles/balancier.xml`.

---

## Entraîner, exporter, téléverser

```
python 07_ppo.py --actionneur couple --pas 9000000
python 08_agent.py --duel
python 11_export_c.py --agent agents/balancier_final.zip
python 12_valider_c.py
```

L'agent final a été entraîné en 15,7 min pour 9 M de pas (Ryzen 7 7800X3D,
16 environnements, CPU seul). `12_valider_c.py` doit annoncer un écart de
l'ordre de 10⁻⁷ : c'est la différence float32 / float64, rien d'autre. **Ne
jamais téléverser un en-tête qui n'est pas passé par lui** : une matrice
transposée ne se voit pas autrement qu'en regardant le robot tomber.

### Les agents versionnés

| | |
|---|---|
| `agents/balancier_final.zip` | l'agent actuel, entraîné sur le moteur fidèle. C'est lui qui est dans `politique.h`. |
| `agents_v1_vitesse/balancier_9000000_pas.zip` | l'ancien, entraîné sur l'actionneur en vitesse. Gardé pour la comparaison (`film.py --comparer`). |

Les jalons intermédiaires, les journaux d'entraînement et les rendus ne sont pas
versionnés : ils se régénèrent.

---

## Résultats

Tous jugés sur le moteur fidèle, robot calme :

| | ancien agent | **nouvel agent** | double PID |
|---|---|---|---|
| erreur d'angle, écart-type | 1,743° | **0,106°** | 0,185° |
| commande, écart-type | 873 pas/s | **47 pas/s** | 86 pas/s |
| dérive de position | 55 mm | 12 mm | 13 mm |
| survie à difficulté 1,0 | 25 % | **42 %** | 33 % |

Poussée isolée de 150 ms à 21 cm de l'axe (`17_pousser_agents.py`) : double PID
0,47 N, ancien agent 0,38 N, nouvel agent 0,53 N. **Mais cet avantage ne
survit pas à un enchaînement de poussées** : à 0,55 N les deux tombent, à 0,50 N
les deux tiennent. La vidéo ne montre donc pas de différence de poussée, parce
qu'il n'y en a pas de robuste. Ce qui s'y voit est la vraie différence : le
tremblement.

Le détail de chaque chiffre est dans [`docs/journal/RESULTATS.md`](../docs/journal/RESULTATS.md),
les erreurs commises en route dans [`docs/journal/PIEGES.md`](../docs/journal/PIEGES.md).

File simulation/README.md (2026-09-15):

# Simulation and learning

**English** · [Français](README.fr.md)

The robot rebuilt in MuJoCo from its SolidWorks assembly, the firmware's dual
PID ported as-is as a reference, and a PPO policy trained to beat it, then
exported to C for the ESP32. Script names and code comments are in French.

**Run every script from this folder.**

```
pip install -r requirements.txt
pip install torch --index-url https://download.pytorch.org/whl/cpu
```

---

## The robot model

**`modeles/balancier.xml`**: the robot in MJCF, MuJoCo's XML format. It is
generated by `modele.py`, never edited by hand, and loads the meshes from
`hardware/cao/stl_assemblage/`. This file uses MuJoCo's simple velocity
actuator; the faithful stepper motor model used for training is added by
`modele.xml('couple')` and `moteur.py`.

There is no URDF: nothing in this project uses ROS.

## The principle

A policy trained on a wrong model learns to balance a robot that does not
exist, and nobody notices until the transfer. So the model is validated
**before** training, and every value records where it comes from:

```
python modele.py --etat
```

`MESURE` (measured on the robot, from a datasheet or the assembly), `DEDUIT`
(derived from a measurement), `ESTIME` (estimated), `SUPPOSE` (assumed). 2 of
the 24 parameters are still not established.

The geometry is not typed in: the 6 STL files in
`hardware/cao/stl_assemblage/` carry the mass, and MuJoCo computes the inertia
from the actual shape.

## The motor, the part that changed everything

A stepper motor is not a speed source. It is a **magnetic spring** between the
commanded position and the rotor position:

```
T = T_holding · sin(50 · (θ_command − θ_rotor))
```

This spring resonates. The resonance was **measured at 71 Hz** on the robot, not
the 113 Hz assumed at first, using frequency sweeps injected in closed loop and
cross-spectra, without taking the robot apart. With MuJoCo's `<velocity>`
actuator, the old policy looked perfect. On the robot, it shook ten times more.
With `moteur.py`, the simulation reproduces that shaking to within 1% on the
command, without ever being fitted to it.

---

## The scripts, in the order of the project

| | |
|---|---|
| `modele.py` | generates the MJCF, records where every number comes from |
| `moteur.py` | the faithful stepper model: magnetic spring, stall |
| `etat.py` | reads the state **through the simulated sensors**, never through `qpos` |
| `firmware.py` | the `.ino` dual PID transcribed to Python |
| `balancier_env.py` | the Gymnasium environment: 15 observations, 2 actions, curriculum |
| `01_regarder.py` | the viewer (`--pousser`, `--mesh`) |
| `02_identifier.py` | the model's natural mode, compared with the notebook |
| `03_pid.py` | the firmware's dual PID in simulation (`--vue`, `--silence`) |
| `04_pousser.py` | the largest push it survives (`--balayage`) |
| `05_bac_a_sable.py` | push the robot with the mouse |
| `06_env.py` | environment check (`--cascade`) |
| `07_ppo.py` | training |
| `08_agent.py` | watch a policy (`--duel` against the dual PID, `--film`) |
| `09_piloter.py` | drive in simulation with a control panel |
| `10_limites.py` | how far each controller holds |
| `11_export_c.py` | exports the policy to C, **straight into** `firmware/robot_balancier/politique.h` |
| `12_valider_c.py` | compiles the header with gcc and compares it with PyTorch |
| `15_moteur_identique.py` | checks that the fast motor copy in `balancier_env.py` gives exactly the torque of `moteur.py` |
| `17_pousser_agents.py` | the largest push for each controller, on the faithful motor |
| `incertitude.py` `moteur_duel.py` `bench_rl.py` | uncertainty propagation, velocity versus torque actuator, PPO throughput |
| `film.py` `rendu.py` | simulation videos |
| `montage_reel.py` `montage_duo.py` `19_mosaique_verticale.py` `montage_post.py` | editing of the published video |

After any change to `modele.py`: `python modele.py` to regenerate
`modeles/balancier.xml`.

---

## Train, export, flash

```
python 07_ppo.py --actionneur couple --pas 9000000
python 08_agent.py --duel
python 11_export_c.py --agent agents/balancier_final.zip
python 12_valider_c.py
```

The final policy was trained in 15.7 min for 9 M steps (Ryzen 7 7800X3D,
16 environments, CPU only). `12_valider_c.py` must report a difference around
10⁻⁷: that is the float32 / float64 difference, nothing else. **Never flash a
header that has not been through it**: a transposed matrix shows up no other way
than by watching the robot fall.

### Versioned policies

| | |
|---|---|
| `agents/balancier_final.zip` | the current policy, trained on the faithful motor. This is the one in `politique.h`. |
| `agents_v1_vitesse/balancier_9000000_pas.zip` | the old one, trained on the velocity actuator. Kept for comparison (`film.py --comparer`). |

Intermediate checkpoints, training logs and renders are not versioned: they can
be regenerated.

---

## Results

All evaluated on the faithful motor, robot at rest:

| | old policy | **new policy** | dual PID |
|---|---|---|---|
| tilt error, standard deviation | 1.743° | **0.106°** | 0.185° |
| command, standard deviation | 873 steps/s | **47 steps/s** | 86 steps/s |
| position drift | 55 mm | 12 mm | 13 mm |
| survival at difficulty 1.0 | 25% | **42%** | 33% |

Single 150 ms push, 21 cm above the axle (`17_pousser_agents.py`): dual PID
0.47 N, old policy 0.38 N, new policy 0.53 N. **But this advantage does not
survive a sequence of pushes**: at 0.55 N both fall, at 0.50 N both hold. So the
video shows no difference in push resistance, because there is no robust one.
What it does show is the real difference: the shaking.

Every number is detailed in [`docs/journal/RESULTATS.md`](../docs/journal/RESULTATS.md),
the mistakes made along the way in [`docs/journal/PIEGES.md`](../docs/journal/PIEGES.md)
(both in French).

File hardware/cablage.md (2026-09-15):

# Câblage

[English](wiring.md) · **Français**

```mermaid
flowchart LR
    BAT["Pack 4S 18650<br/>14,8 V"]
    CONV["Convertisseur<br/>5 V"]
    ESP["ESP32<br/>WROOM-32D"]
    IMU["MPU-6050"]
    DD["A4988<br/>roue droite"]
    DG["A4988<br/>roue gauche"]
    MD["NEMA 17<br/>droite"]
    MG["NEMA 17<br/>gauche"]

    BAT -- "VMOT, 100 µF" --> DD
    BAT -- "VMOT" --> DG
    BAT --> CONV -- "5 V sur VIN" --> ESP
    ESP -- "3,3 V vers VDD" --> DD
    ESP -- "3,3 V vers VDD" --> DG
    ESP -- "STEP 18, DIR 5" --> DD
    ESP -- "STEP 16, DIR 17" --> DG
    DD --> MD
    DG --> MG
    ESP <-- "SDA 21, SCL 22" --> IMU
    IMU -- "INT vers GPIO 19" --> ESP
```

Toutes les masses sont communes.

Le convertisseur abaisse la tension du pack à 5 V et entre sur la broche
**VIN** de l'ESP32, dont le régulateur produit le 3,3 V qui alimente aussi
l'IMU et la logique des drivers.

---

## ESP32

Brochage lu dans `firmware/robot_balancier/robot_balancier.ino`.

| signal | GPIO | remarque |
|---|---|---|
| STEP moteur 1, **roue droite** | 18 | |
| DIR moteur 1 | 5 | |
| STEP moteur 2, **roue gauche** | 16 | |
| DIR moteur 2 | 17 | |
| INT du MPU-6050 | 19 | cadence la boucle à 200 Hz |
| SDA | 21 | I2C à **100 kHz** : 400 kHz s'est révélé inutilisable avec ce câblage |
| SCL | 22 | |

## MPU-6050

| broche | connexion |
|---|---|
| VCC | 3,3 V |
| GND | masse |
| SDA, SCL | GPIO 21, 22 |
| INT | GPIO 19 |
| AD0 | masse, d'où l'adresse 0x68 |

## A4988, identiques pour les deux roues

| broche | connexion | conséquence |
|---|---|---|
| VMOT | batterie, 14,8 V | condensateur de 100 µF au plus près |
| VDD | 3,3 V de l'ESP32 | **ne pas passer au 5 V** : le seuil logique haut deviendrait 3,5 V, au-dessus de ce que sort l'ESP32 |
| MS1, MS2 | 3,3 V | micropas 1/8 |
| MS3 | non connectée | tirée à la masse en interne par l'A4988 |
| RESET | ponté sur SLEEP | sort le driver de veille |
| ENABLE | non connecté | drivers toujours actifs |
| 1A, 1B | fils noir et vert | bobine 1 |
| 2A, 2B | fils rouge et bleu | bobine 2 |

**Le micropas.** 1 600 pas par tour ont été **mesurés** sur le robot le
9 septembre 2026, soit du 1/8 de pas. Sur l'A4988, le 1/8 correspond à MS1 et
MS2 au niveau haut et MS3 au niveau bas : toutes les broches MS ne sont donc
pas câblées. Le carnet d'origine notait les trois au 3,3 V, ce qui aurait donné
du 1/16 et 3 200 pas par tour. La mesure l'a contredit, et le montage confirme
le 1/8.

Une bobine du moteur droit est inversée au câblage, d'où `INVERT_M1` et
`INVERT_M2` laissés à `false` dans le code.

---

## Ce qui a été appris sur le câblage

Le taux d'échec I2C dépendait de la **position des fils** : il est passé de 0 à
1,6 lecture ratée par seconde le soir où le robot a simplement été posé sur un
support. Les moteurs sont les principaux émetteurs de bruit.

Ce qui a réglé le problème côté logiciel : la lecture I2C tourne dans une tâche
séparée, et une lecture ratée n'arrête plus les moteurs. Depuis, 0 échec au
repos.

Recommandations restées ouvertes, par coût croissant :

- torsader les deux fils de chaque bobine moteur, gratuit ;
- éloigner les fils I2C des câbles moteurs, les croiser à 90° si besoin ;
- 10 kΩ de rappel vers la masse sur chaque STEP (GPIO 18 et 16) : au démarrage
  de l'ESP32 les broches flottent, et chaque parasite devient un pas ;
- découpler le VDD de chaque driver, 100 nF et 10 µF au ras du composant.

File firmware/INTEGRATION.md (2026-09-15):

# Mettre la politique sur l'ESP32

Tout ce qu'il faut faire, dans l'ordre. Les seuils ne sont pas choisis à
l'estime : chacun est mesuré, et la mesure est indiquée.

---

## 1. Ce qu'est le fichier `politique.h`

Un en-tête C autonome, 39 ko de source, **aucune dépendance hors `math.h`**.

| | |
|---|---|
| `pol_w0/b0` `pol_w1/b1` `pol_w2/b2` | les 1 634 poids, en `static const float` → **flash, pas RAM** |
| `pol_avant()` | l'inférence : 1 568 multiplications-accumulations, 64 `tanh` |
| `politique_observation()` | construit les 15 entrées depuis ce que le robot mesure |
| `politique_accel()` | l'appel de haut niveau → une accélération en pas/s² |
| `politique_reset()` | **à appeler à chaque armement** |
| `politique_defaut` | 0 si tout va bien, sinon le code du garde-fou déclenché |

Régénérer après tout réentraînement :

```
python 11_export_c.py            # écrit firmware/robot_balancier/politique.h
python 12_valider_c.py           # compile et compare au Python
```

**Ne jamais téléverser sans avoir lancé `12_valider_c.py`.** Il compile
l'en-tête avec gcc, lui donne 2 400 observations issues d'épisodes réels, et
compare aux actions de `stable-baselines3`. Écart mesuré sur l'export actuel :
**2,1 × 10⁻⁷**, c'est-à-dire la différence float32/float64 et rien d'autre.
Une matrice transposée ou une activation inversée ne se voit pas autrement
qu'en regardant le robot tomber.

---

## 2. Ce que l'agent remplace, et ce qu'il ne remplace pas

Il se substitue à **la boucle interne**, au même point d'insertion :

```
avant   accel = Kp_a*err + Ki_a*angleIntegral + Kd_a*gyroFilt;
après   accel = politique_accel(...);
        wheel_sps += accel * dt;              ← inchangé
```

**Il remplace aussi la boucle externe.** L'agent a l'écart de position et la
consigne de vitesse dans son observation — il fait déjà ce travail. Donc quand
il pilote : pas d'`outerLoop()`, pas d'auto-trim.

L'auto-trim est le point à ne pas rater : il déplace `angleOffset`, or l'agent
lit `pitch - angleOffset`. Le laisser courir reviendrait à faire bouger sa
référence de verticale sous ses pieds pendant qu'il travaille.

**Tout le reste ne bouge pas** : le timer, l'ISR, l'homme mort, le filtre
complémentaire, la calibration gyro, la télémétrie, le chien de garde, les
sécurités I2C.

### Ce que l'agent n'a pas, et ce que ça coûte

Ton firmware lit 8 octets depuis `0x3D` : `AY AZ TEMP GX`. Donc pas de gyro Z,
et la politique a été entraînée sans odométrie par roue. Trois entrées sur
quinze sont câblées à zéro. Mesuré en simulation :

| | survie | erreur d'angle |
|---|---|---|
| toutes les entrées | 100 % | 0,086° |
| sans lacet ni cap — **ton robot** | 100 % | 0,085° |

Et lier les deux roues : 0,089° contre 0,088°. **Aucun coût.**

La direction ajoutée le 10 septembre 2026 (commande `#`) s'applique **après** la
politique, en écartant les vitesses des deux roues : l'agent ne la voit pas.

---

## 3. LE test à faire en premier : le signe

C'est le seul point qui peut détruire le robot, et il ne se vérifie pas en
simulation. Si le signe de l'angle est inversé, l'agent accélère du mauvais
côté et le robot part par terre en une demi-seconde, à pleine vitesse.

**Roues en l'air, robot tenu à la main. Commande `3`.**

Le mode test n'envoie rien aux moteurs : il affiche seulement ce que l'agent
*voudrait* faire.

```
penche le robot vers l'AVANT   →  accel doit être POSITIVE
penche le robot vers l'ARRIÈRE →  accel doit être NÉGATIVE
```

C'est contre-intuitif à l'arrêt mais c'est bien ça : pour rattraper un robot
qui tombe en avant, il faut accélérer les roues **vers l'avant**, pour ramener
le point d'appui sous le centre de masse.

**La table de référence**, mesurée sur l'export, gyro et vitesse nuls. C'est
exactement ce que le mode `3` doit afficher :

| angle | accel attendue |
|---|---|
| −10° | −14 830 pas/s² |
| −6° | −14 042 |
| −3° | −10 694 |
| −1° | −4 133 |
| 0° | +444 |
| +1° | +4 775 |
| +3° | +10 404 |
| +6° | +13 215 |
| +10° | +13 556 |

Si tu lis des signes opposés, le signe est inversé — voir § 6. Si tu lis des
valeurs très différentes **au même signe**, c'est que `angleOffset` n'est pas
au bon endroit : refais un `Z` robot bien vertical.

---

## 4. Les garde-fous

Trois, tous vérifiés sur le C compilé.

| code | déclencheur | pourquoi ce seuil |
|---|---|---|
| `POL_DEFAUT_ANGLE` | \|angle\| > **14°** | l'agent rattrape 6/6 à 10°, **0/6 à 12°**. Au-delà c'est perdu, autant couper que le laisser s'acharner. |
| `POL_DEFAUT_SATURE` | \|action\| > 0,98 pendant > **120 ms** | en marche normale l'action ne sature **jamais** : 0,0 % du temps, même très perturbé. Aucun faux positif possible. |
| `POL_DEFAUT_NAN` | entrée ou sortie non numérique | voir ci-dessous, c'est le plus important. |

### Pourquoi le test NaN n'est pas une précaution de principe

Aucune comparaison avec `NaN` n'est vraie. Si `wheel_sps` devient `NaN`, dans
`applyMotorSpeed()` :

```c
if (a < MIN_SPS)  → faux   →  il ne coupe pas les moteurs
if (a > lim)      → faux   →  il ne borne pas non plus
half = (uint32_t)(500000.0f / NaN)   →  indéfini
if (half < 20) half = 20;            →  20 µs de demi-période
```

**Soit 25 000 pas/s, moteurs à fond, toutes les bornes traversées en silence.**
Le garde-fou est en amont *et* en aval du réseau.

Ce risque existe aussi avec ta cascade — il est juste moins probable.

### Ce qu'il faut en faire

`politique_accel()` retourne **0** quand un garde-fou mord, et pose le code
dans `politique_defaut`. Le traitement recommandé, dans `innerLoop()` :

```c
if (politique_defaut != POL_OK) {
  pidEnabled = false;
  dualPid = false;
  pendingArm = autoRearm;        // il se relèvera seul si H est actif
  resetLoops();                  // coupe les moteurs, remet tout à zéro
  Serial.print(F(">>> AGENT COUPE, defaut "));
  Serial.println(politique_defaut);
}
```

`resetLoops()` appelle déjà `applyMotorSpeed(0)` : **les moteurs s'arrêtent
dans le même tour de boucle.**

### Ce qui protège déjà, et qui reste actif

| | |
|---|---|
| `FALL_LIMIT` 30° | la chute franche |
| `SAT_MAX_MS` 1500 ms | vitesse saturée = roues dans le vide |
| `i2cFailStreak >= 10` | capteur muet |
| chien de garde IMU 40 ms | plus de données → moteurs coupés |
| `DEADMAN_TICKS` dans l'ISR | la boucle se bloque → l'ISR s'arrête seule |
| chien de garde matériel 2 s | blocage → redémarrage |

Les garde-fous de l'agent viennent **avant** ceux-là, pas à leur place.

---

## 5. Le patch, bloc par bloc

### a) en tête de fichier

```c
#include "politique.h"

bool useAgent = false;      // false = ta cascade, true = l'agent
bool testSigne = false;     // mode verification roues en l air
```

Mets `politique.h` **dans le dossier du croquis**, à côté du `.ino`.

### b) dans `resetLoops()`, à la fin

```c
  politique_reset();        // vide a(t-1), a(t-2) et la cible de position
```

Sans ça, l'agent redémarre après une chute avec l'action qui la précédait et
une cible de position périmée : il corrige une erreur qui n'existe plus. C'est
le même piège que les échéances en date absolue après un `mj_resetData`.

### c) dans `innerLoop()`, remplacer le calcul de `accel`

```c
void innerLoop(float dt) {
  float err = pitch - target_angle;
  float accel;

  if (useAgent) {
    // La politique decide a 100 Hz, l integrateur reste a 200 Hz.
    static bool tickPol = false;
    static float accelPol = 0.0f;
    tickPol = !tickPol;
    if (tickPol) {
      int32_t pos;
      portENTER_CRITICAL(&timerMux);
      pos = stepCount;
      portEXIT_CRITICAL(&timerMux);
      accelPol = politique_accel(pitch - angleOffset, gyroFilt,
                                 wheel_sps, (long)pos, target_speed_sps,
                                 millis());
      if (politique_defaut != POL_OK) {
        pidEnabled = false; dualPid = false;
        pendingArm = autoRearm;
        resetLoops();
        Serial.print(F(">>> AGENT COUPE, defaut "));
        Serial.println(politique_defaut);
        return;
      }
    }
    accel = accelPol;
    angleIntegral = 0.0f;          // l integrale de la cascade ne sert plus
  } else {
    angleIntegral += err * dt;
    angleIntegral = constrain(angleIntegral, -20.0f, 20.0f);
    accel = Kp_a * err + Ki_a * angleIntegral + Kd_a * gyroFilt;
  }

  // ... tout le reste de innerLoop() est INCHANGE :
  //     accelLimit, wheel_sps += accel*dt, anti-emballement,
  //     surveillance de saturation, applyMotorSpeed(wheel_sps)
}
```

### d) dans `loop()`, ne pas appeler `outerLoop()` quand l'agent pilote

```c
        if (dualPid && !useAgent) {
          if (++outerCounter >= OUTER_DIV) { outerCounter = 0; outerLoop(dt * OUTER_DIV); }
        } else {
          target_angle = angleOffset;
          speed_angle_corr = 0.0f;
        }
        innerLoop(dt);
```

### e) trois commandes série

Toutes les lettres sont prises dans ton firmware — j'utilise des chiffres.

```c
    case '1':
      useAgent = false; testSigne = false; resetLoops();
      Serial.println(F("pilote = CASCADE"));
      break;

    case '2':
      useAgent = true; testSigne = false; resetLoops();
      Serial.println(F("pilote = AGENT"));
      break;

    case '3':
      testSigne = !testSigne;
      pidEnabled = false; dualPid = false; resetLoops();
      Serial.println(testSigne
        ? F("TEST DE SIGNE : roues en l air. Penche le robot, lis 'a'.")
        : F("test de signe termine"));
      break;
```

### f) le mode test de signe, dans `loop()`

À placer dans le bloc `if (mpuDataReady)`, juste avant la télémétrie :

```c
    if (testSigne) {
      float a = politique_accel(pitch - angleOffset, gyroFilt,
                               0.0f, 0L, 0.0f, millis());
      if (millis() - lastSigneMsg > 200) {
        lastSigneMsg = millis();
        Serial.print(F("angle ")); Serial.print(pitch - angleOffset, 2);
        Serial.print(F(" deg   ->   a "));  Serial.print(a, 0);
        Serial.println(F(" pas/s2   (avant => POSITIF attendu)"));
      }
    }
```

Rien n'est envoyé aux moteurs dans ce mode.

### g) ajouter le pilote à la télémétrie

```c
    Serial.print(useAgent ? F(" AGENT") : F(" PID"));
```

Sans ça tu ne sauras pas qui pilote en relisant un log — et on s'est déjà fait
prendre par un mode qui avait basculé silencieusement.

---

## 6. Si le signe est inversé

Une seule ligne à changer, dans le patch :

```c
politique_accel(-(pitch - angleOffset), -gyroFilt, ...)
```

**Les deux ensemble.** L'angle et sa dérivée doivent garder le même signe
relatif, sinon le terme dérivé travaille à contresens.

---

## 7. L'ordre des essais

| | quoi | critère de passage |
|---|---|---|
| 1 | `12_valider_c.py` sur le PC | écart < 2×10⁻⁵ |
| 2 | téléverser, `?` pour vérifier que ça démarre | pas de reset, `hz:200`, `f:0` |
| 3 | **`3`, roues en l'air, pencher à la main** | avant → `a` positif |
| 4 | `1` puis `K` — la cascade, comme d'habitude | il tient, référence de comparaison |
| 5 | **`2` puis `K`, robot tenu à la main**, prêt à le rattraper | il ne s'emballe pas |
| 6 | `2`, `K`, lâché, au sol, sur une surface dégagée | il tient |
| 7 | poussées légères, puis `N 300` pour un déplacement | |

Ne saute pas l'étape 3. C'est la seule qui protège le matériel.

Et garde `1` sous la main : une frappe et tu es revenu sur la cascade, sans
réarmer.

---

## 8. Ce qui reste incertain, honnêtement

**Le coût en temps sur la carte n'est pas mesuré.** 1 568 MAC ≈ 13 µs à
240 MHz, mais les 64 `tanhf()` viennent de newlib et coûtent probablement
1 à 2 µs chacun — soit **100 à 140 µs par pas de politique**, une fois sur deux.
Ton log actuel montre `Lus:2172` au pire pour un budget de 5 000 µs : la marge
est de 2 828 µs, donc même 140 µs ne représentent que **5 %**. Mais regarde
`Lus` après le téléversement, c'est la mesure qui tranche.

Si c'est trop cher : `python 11_export_c.py --tanh-rapide` remplace `tanhf` par
une approximation de Padé, environ dix fois plus rapide. Relance
`12_valider_c.py` derrière pour chiffrer ce que l'approximation coûte en
précision.

**Le modèle n'a toujours pas été validé contre la mesure du pendule suspendu.**
Les masses restent estimées. L'agent a été entraîné avec ±30 % dessus, donc il
devrait encaisser — mais ce n'est pas une preuve.

**Un point que ton log de ce soir a révélé :** ton `Ki_spd` vaut 0,0005 et non
0,0008, et l'auto-trim absorbait une correction de position de −0,92° au rythme
de 0,045°/s. Sans importance pour l'agent, qui n'utilise ni l'un ni l'autre.

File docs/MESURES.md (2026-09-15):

# Ce qu'il reste à mesurer

> **Mise à jour.** Les masses ne sont plus pesées mais **estimées**, et
> `incertitude.py` montre que ça suffit : la fourchette à 90 % sur les
> 20 oscillations est de **16,1 à 17,2 s**, soit −4 / +3 %. Peser n'apporterait
> presque rien. La seule mesure qui reste indispensable est la **n° 1**.

**L'export d'assemblage a réglé toute la géométrie.** Les 6 STL partagent le
repère de l'assemblage, l'arbre du moteur 1 a été localisé dans le maillage
(cylindre de 5,00 mm), et les maillages portent maintenant la masse — MuJoCo
calcule leur tenseur d'inertie sur la vraie forme.

Il ne reste donc **que des masses**, plus aucune forme — et elles sont estimées
à partir du volume des STL et de l'épaisseur de paroi, pas devinées.

`python modele.py --etat` liste les sources. `python incertitude.py` dit ce que
chaque incertitude coûte réellement.

---

## 1. La période du pendule suspendu — 10 minutes

C'est **la** mesure, et elle vaut contre-épreuve de tout le reste. Elle donne
directement le chiffre que la commande doit combattre, sans balance ni calcul.

**Protocole.** Serrer l'essieu horizontalement dans un étau ou entre deux livres,
roues démontées ou bloquées, le robot **pendant vers le bas**. L'écarter de 5 à
10° et lâcher. Chronométrer **20 oscillations complètes**.

```
T = t(20 oscillations) / 20
ω = 2π / T
```

**Pourquoi ça marche.** Suspendu, le robot est un pendule composé de période
`T = 2π·√(I/(m·g·d))`. Retourné, il diverge à `ω = √(m·g·d/I)` — **le même
groupement**, à l'inverse près. Donc :

> Le taux de divergence du pendule inversé est exactement `2π/T`,
> où `T` est la période du même robot suspendu.

Pas d'algèbre, pas de masse à peser, pas de centre de gravité à trouver. On
compte des allers-retours.

Amplitude sous 10° (au-delà la période s'allonge), et 20 périodes pour que
l'erreur de chronométrage humaine (~0,2 s) tombe sous 1 %.

**Ce que le modèle prédit :** `T = 0,833 s`, soit **20 oscillations en 16,7 s**,
et `ω = 7,54 rad/s`. Fourchette à 90 % compte tenu de toutes les estimations :
**16,1 à 17,2 s**.

- **entre 16 et 17,5 s** → le modèle est validé, on passe au RL sans rien peser ;
- **en dehors** → quelque chose de structurel cloche, et là on cherche.

`python 02_identifier.py` réaffiche la prédiction, `python incertitude.py`
réaffiche la fourchette, à chaque modification du modèle.

## 2. Contre-épreuve : la chute libre — 2 minutes, robot complet

Celle du dessus se fait sur l'établi, roues démontées. Celle-ci se fait sur le
robot entier, posé au sol.

```
S                      désarmer le PID
                       caler le robot à ~1° de l'équilibre, lâcher
                       relever dans logs/robot.log l'instant où P passe 10°
ω = arccosh(10/1) / t  = 2,993 / t
```

Ce n'est **pas** la même grandeur que la mesure 1 : ici le robot peut translater,
le pivot se déplace. Le modèle prédit `ω = 10,0 rad/s`, soit **299 ms** pour aller
de 1° à 10°. Trois lâchers, on garde la médiane.

## 3. Le micropas : 1600 ou 3200 ? — 3 minutes

Le carnet laisse la question ouverte, et elle vaut un **facteur deux sur toutes
les distances**.

Multimètre sur MS1/MS2/MS3 : les trois au 3,3 V = 1/16 = 3200 pas/tour. Le carnet
dit que c'est le câblage constaté — donc 3200 est le plus probable, et le firmware
ment.

Contre-épreuve : repère au feutre sur une roue, robot roues en l'air, `V 60`.
Chronométrer 30 tours. 30 s → 1600 pas/tour. 60 s → 3200.

---

## 4. Les masses — devenu optionnel

`incertitude.py` classe les paramètres par leur effet réel sur `T` :

| Paramètre | Effet sur T | |
|---|---|---|
| `masse_bat_haut` | **4,9 %** | 3 cellules : 14500 (20 g) ou 18650 (45 g) ? |
| `h_bat_haut` | **4,0 %** | hauteur du pack, ±12 mm |
| `masse_elec` | 2,2 % | Labdec + ESP32 + drivers |
| tout le reste réuni | < 1,3 % chacun | |

**Les trois premiers pèsent 66 % de l'incertitude.** Le type de cellule et la
hauteur du pack, c'est-à-dire deux choses qui se règlent à l'œil et au mètre
ruban, pas à la balance :

- **quelle cellule ?** Ø18 × 65 mm = 18650, 45 g. Ø14 × 50 mm = 14500, 20 g.
- **à quelle hauteur** est le centre du paquet de 3, depuis l'axe des roues ?

Peser les pièces imprimées ne changerait `T` que de 1 % au total. Ça ne vaut pas
le démontage.

<details>
<summary>Si tu veux quand même peser — le tableau</summary>

Balance de cuisine à 1 g près. Les volumes viennent des STL, donc une seule
pièce pesée suffit : on en déduit la densité effective et on répartit au prorata.

Les masses actuelles ne sont pas devinées : le volume vient du STL, et la densité
effective de l'**épaisseur caractéristique** `2V/A` de chaque pièce. Une pièce
mince est presque toute en périmètres, donc dense ; une pièce épaisse est surtout
du remplissage, donc légère.

| | volume | 2V/A | densité | masse |
|---|---|---|---|---|
| `piece1` | 92,8 cm³ | 8,01 mm | 0,45 | 41 g |
| `piece2` | 65,2 cm³ | 4,15 mm | 0,63 | 41 g |
| `piece3` | 118,1 cm³ | 5,04 mm | 0,56 | 67 g |
| `piece4` | 103,5 cm³ | 6,17 mm | 0,51 | 52 g |

Total PLA **201 g**. Robot complet estimé à **986 g**.

</details>

## 5. Où sont les piles et la Labdec — 5 minutes, mètre ruban

Les seules géométries absentes de la CAO, et les plus sensibles de la liste : le
bras de levier intervient **au carré** dans l'inertie.

Placement actuel, déduit de ce que tu m'as décrit (`piece4` va de +136 à
+199 mm de l'axe) :

| | Paramètre | Actuel | D'où |
|---|---|---|---|
| 3 cellules **posées sur** la pièce du haut | `h_bat_haut` | 208 mm | +199 + 9 de rayon |
| 1 cellule **collée sous** la pièce du haut | `h_bat_bas` | 127 mm | +136 − 9 |
| la Labdec | `h_elec` | 110 mm | **inventé — la seule position encore devinée** |

`h_elec` est le dernier chiffre sans aucune source. Il pèse 1,3 % sur `T`, donc
ce n'est pas urgent, mais c'est 30 secondes de mètre ruban.

## 6. L'adhérence — 3 minutes, optionnel

Robot désarmé sur une planche qu'on incline jusqu'au glissement :
`µ = tan(angle)`. Provisoire : `frottement = 1.0`.

Optionnel parce que la randomisation de domaine balaiera ce paramètre de toute
façon. Utile seulement si tu soupçonnes du patinage — ton carnet n'en mentionne
aucun.

## 7. Le bruit des capteurs — déjà dans tes logs

`bruit_gyro = 0,019 rad/s` vient du carnet (1,08 °/s d'écart-type). Pour
`bruit_accel`, il faudrait logger `ay`/`az` bruts pendant que les moteurs tournent
à vitesse constante, roues en l'air.

C'est ce bruit-là qui fixe l'écart entre les **0,003°** d'erreur de la simulation
et tes **0,064°** réels. Il n'entrera pas dans le modèle nominal, mais dans la
randomisation.

---

## Le test de recette

Une fois les valeurs saisies dans `modele.py` :

```
python modele.py                 régénère le XML depuis l'assemblage
python 02_identifier.py          ω doit valoir 2π/T mesuré
python 03_pid.py --silence       la cascade doit tenir avec TES gains
python rendu.py --pid 8          et ça doit ressembler à ton robot
```

Si `03_pid.py` tient debout avec `Kp=4500, Ki=40, Kd=600` **sans rien retoucher**,
le modèle est validé pour la commande. C'est le feu vert pour le RL — pas avant.

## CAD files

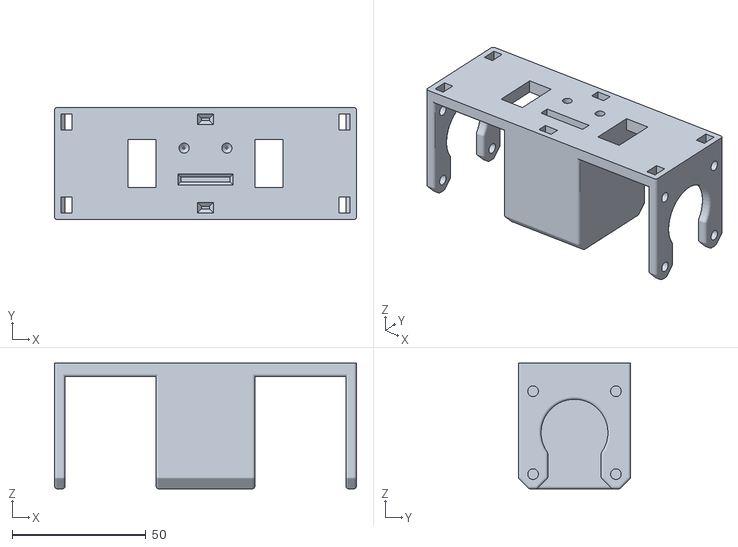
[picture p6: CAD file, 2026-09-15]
hardware/cao/stl_assemblage/Assemblage1 - piece1-1.STL
113.0 x 42.0 x 47.0

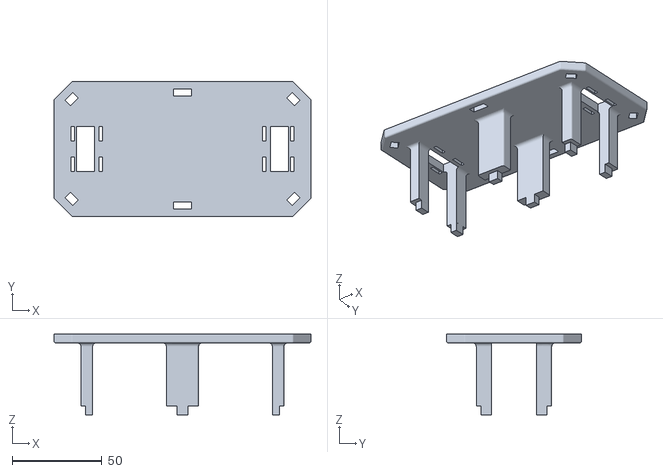
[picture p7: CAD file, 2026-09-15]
hardware/cao/stl_assemblage/Assemblage1 - piece2-1.STL
143.0 x 75.0 x 45.0

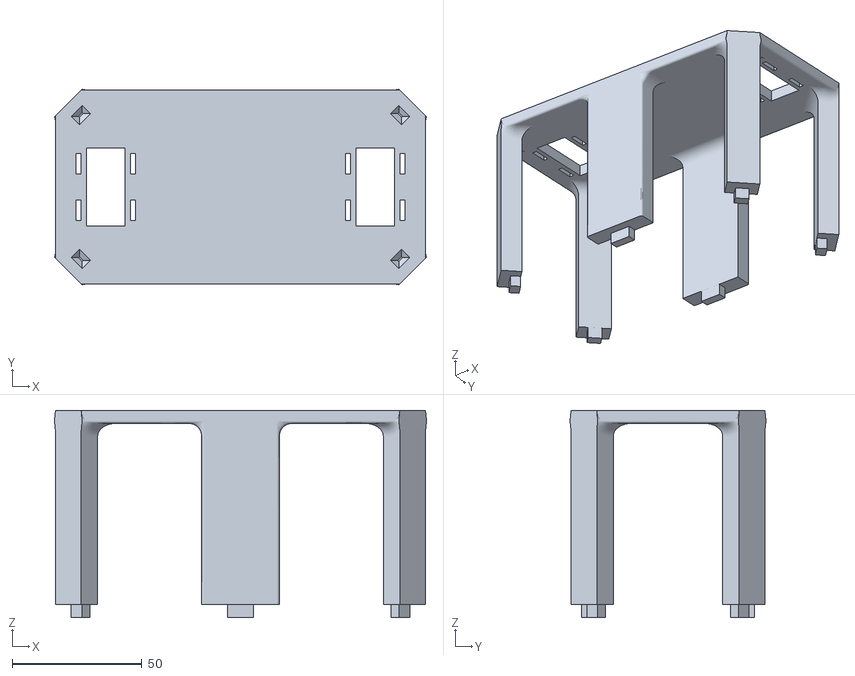
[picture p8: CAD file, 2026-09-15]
hardware/cao/stl_assemblage/Assemblage1 - piece3-1.STL
143.6 x 75.6 x 80.0

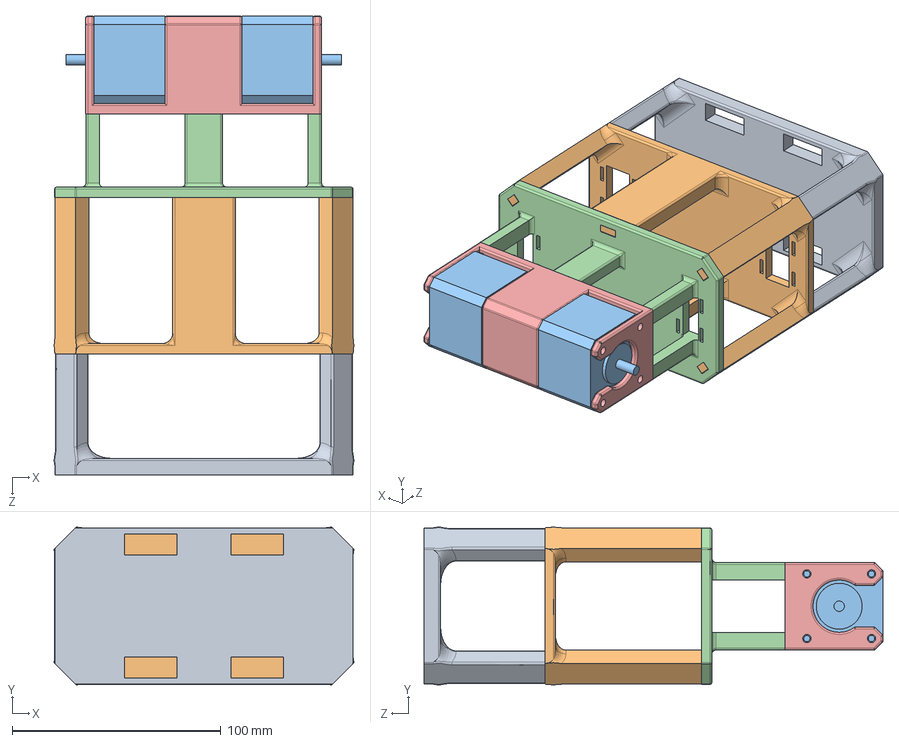
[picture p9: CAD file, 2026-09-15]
hardware/cao/solidworks/Assemblage1.SLDASM
143.7 x 75.7 x 220.0 mm
piece1
piece2
nema17HS3401S x 2
piece3
piece4

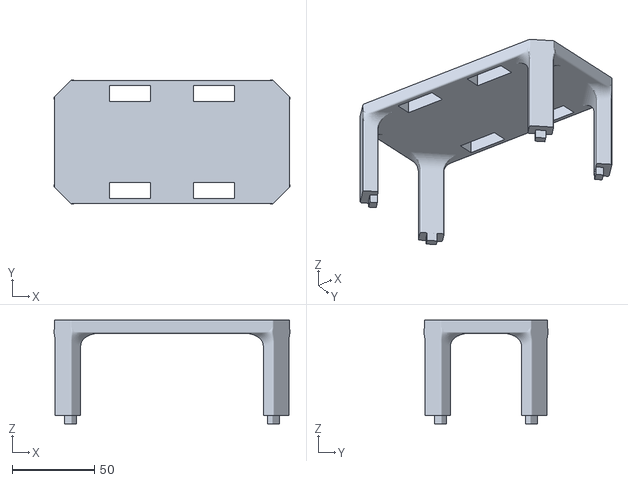
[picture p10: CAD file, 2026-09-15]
hardware/cao/stl_assemblage/Assemblage1 - piece4-1.STL
143.7 x 75.7 x 63.0

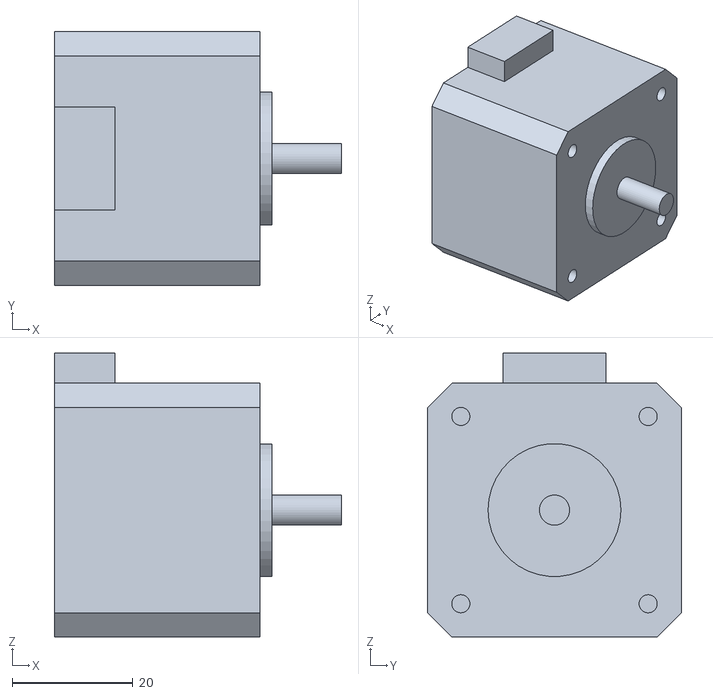
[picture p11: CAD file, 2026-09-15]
hardware/cao/stl_assemblage/Assemblage1 - nema17HS3401S-2.STL
47.5 x 42.0 x 47.0

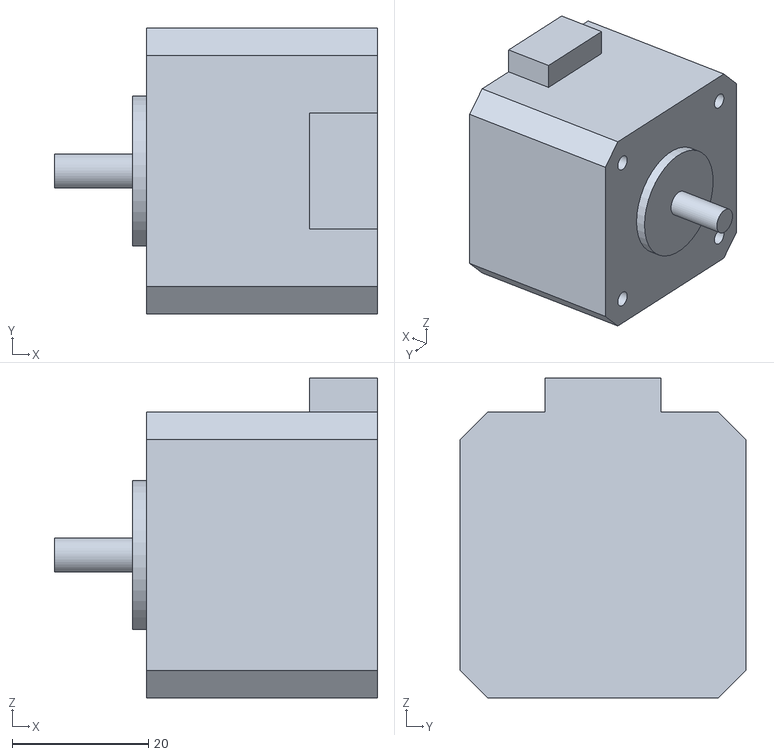
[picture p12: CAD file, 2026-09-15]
hardware/cao/stl_assemblage/Assemblage1 - nema17HS3401S-1.STL
47.5 x 42.0 x 47.0

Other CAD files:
hardware/cao/solidworks/piece3.SLDPRT
hardware/cao/solidworks/piece2.SLDPRT
hardware/cao/solidworks/piece4.SLDPRT
hardware/cao/solidworks/piece1.SLDPRT
hardware/cao/solidworks/nema17HS3401S.SLDPRT
hardware/cao/stl/piece1.STL
hardware/cao/stl/piece2.STL
hardware/cao/stl/piece3.STL
hardware/cao/stl/piece4.STL

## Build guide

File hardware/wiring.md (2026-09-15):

# Wiring

**English** · [Français](cablage.md)

```mermaid
flowchart LR
    BAT["18650 pack 4S<br/>14.8 V"]
    CONV["Converter<br/>5 V"]
    ESP["ESP32<br/>WROOM-32D"]
    IMU["MPU-6050"]
    DD["A4988<br/>right wheel"]
    DG["A4988<br/>left wheel"]
    MD["NEMA 17<br/>right"]
    MG["NEMA 17<br/>left"]

    BAT -- "VMOT, 100 µF" --> DD
    BAT -- "VMOT" --> DG
    BAT --> CONV -- "5 V to VIN" --> ESP
    ESP -- "3.3 V to VDD" --> DD
    ESP -- "3.3 V to VDD" --> DG
    ESP -- "STEP 18, DIR 5" --> DD
    ESP -- "STEP 16, DIR 17" --> DG
    DD --> MD
    DG --> MG
    ESP <-- "SDA 21, SCL 22" --> IMU
    IMU -- "INT to GPIO 19" --> ESP
```

All grounds are common.

The converter steps the pack voltage down to 5 V and feeds the ESP32's **VIN**
pin. The board's regulator then produces the 3.3 V that also powers the IMU and
the drivers' logic.

---

## ESP32

Pinout taken from `firmware/robot_balancier/robot_balancier.ino`.

| signal | GPIO | note |
|---|---|---|
| STEP motor 1, **right wheel** | 18 | |
| DIR motor 1 | 5 | |
| STEP motor 2, **left wheel** | 16 | |
| DIR motor 2 | 17 | |
| MPU-6050 INT | 19 | clocks the control loop at 200 Hz |
| SDA | 21 | I2C at **100 kHz**: 400 kHz proved unusable with this wiring |
| SCL | 22 | |

## MPU-6050

| pin | connection |
|---|---|
| VCC | 3.3 V |
| GND | ground |
| SDA, SCL | GPIO 21, 22 |
| INT | GPIO 19 |
| AD0 | ground, hence address 0x68 |

## A4988, identical for both wheels

| pin | connection | consequence |
|---|---|---|
| VMOT | battery, 14.8 V | 100 µF capacitor as close as possible |
| VDD | 3.3 V from the ESP32 | **do not move to 5 V**: the logic high threshold would become 3.5 V, above what the ESP32 outputs |
| MS1, MS2 | 3.3 V | 1/8 microstepping |
| MS3 | not connected | pulled to ground internally by the A4988 |
| RESET | bridged to SLEEP | keeps the driver awake |
| ENABLE | not connected | drivers always active |
| 1A, 1B | black and green wires | coil 1 |
| 2A, 2B | red and blue wires | coil 2 |

**Microstepping.** 1,600 steps per revolution were **measured** on the robot on
9 September 2026, i.e. 1/8 step. On the A4988, 1/8 means MS1 and MS2 high and
MS3 low, so not all MS pins are wired. The original notebook listed all three
at 3.3 V, which would have given 1/16 and 3,200 steps per revolution. The
measurement contradicted it, and the actual wiring confirms 1/8.

One coil of the right motor is swapped in the wiring, which is why `INVERT_M1`
and `INVERT_M2` are left `false` in the code.

---

## What was learned about the wiring

The I2C failure rate depended on **where the wires lay**: it went from 0 to 1.6
failed reads per second the evening the robot was simply placed on a stand. The
motors are the main source of noise.

What fixed it on the software side: I2C reading runs in a separate task, and a
failed read no longer stops the motors. Since then, 0 failures at rest.

Recommendations still open, by increasing cost:

- twist the two wires of each motor coil, free;
- keep the I2C wires away from the motor cables, cross them at 90° if needed;
- a 10 kΩ pull-down on each STEP pin (GPIO 18 and 16): while the ESP32 boots the
  pins float, and every glitch becomes a step;
- decouple each driver's VDD, 100 nF and 10 µF right at the chip.

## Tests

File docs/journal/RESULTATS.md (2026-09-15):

# Tous les chiffres

Chaque nombre porte la commande qui le produit. Aucun n'est estimé de tête.
Établis le **5 septembre 2026**, sur l'agent `balancier_9000000_pas.zip`.

---

## Le modèle

`python 02_identifier.py`

| | |
|---|---|
| masse chassis | 0,928 kg |
| masse totale | 0,988 kg |
| hauteur du CdM / essieu | 74,1 mm |
| inertie au CdM (axe y) | 0,00716 kg·m² |
| inertie à l'essieu | 0,01225 kg·m² |
| **prédiction du pendule suspendu** | **T = 0,83 s, soit 16,6 s pour 20 oscillations** |
| divergence, roues libres | ≈ 10 rad/s |

`python incertitude.py` — fourchette à 90 % compte tenu de toutes les
estimations : **16,2 à 17,1 s**. Les trois paramètres qui dominent :
`masse_bat_haut` (4,9 %), `h_bat_haut` (4,0 %), `masse_elec` (2,4 %).

## La géométrie, lue dans l'assemblage

| | |
|---|---|
| axe des roues, repère assemblage | (74,10 ; 39,68 ; 1021,00) mm |
| entraxe des arbres moteur | 84,5 mm |
| demi-voie retenue | 69,1 mm — **déduite, pas mesurée** |
| emprise | 143,7 × 75,7 × 220 mm |
| hauteur hors-tout depuis le sol | 231,5 mm |
| étagères (surfaces horizontales) | +66, +141, +199 mm de l'essieu |
| volumes imprimés | p1 92,8 · p2 65,2 · p3 118,1 · p4 103,5 cm³ |
| PLA total estimé | 201 g |

## La cascade dans la simulation

`python 03_pid.py --silence`

| | simulation | robot réel (carnet) |
|---|---|---|
| erreur d'angle, écart-type | 0,043° | 0,064° |
| commande, écart-type | 39 pas/s | 46 pas/s |
| bruit gyro mécanique | 0,11 °/s (modèle vitesse) | 1,08 à 3,48 °/s |

Avec le modèle **fidèle** du pas-à-pas (`moteur_duel.py`) : 5,45 °/s de vibration
mécanique, du bon ordre que le réel — le modèle en vitesse n'en produit aucune.

## Le duel agent contre cascade

`python 08_agent.py --duel`

| | AGENT | CASCADE |
|---|---|---|
| **difficulté 0,0** | | |
| erreur d'angle | 0,082° | 0,105° |
| commande, écart-type | 32 | 46 pas/s |
| rugosité (RMS d²a) | 0,0650 | 0,0357 |
| **difficulté 0,6** | | |
| épisodes survécus | **92 %** | 58 % |
| erreur d'angle | 1,086° | 1,959° |
| commande, écart-type | 348 | 466 pas/s |
| rugosité | **0,0623** | 0,1448 |
| **difficulté 1,0** | | |
| épisodes survécus | **42 %** | 25 % |
| erreur d'angle | 2,621° | 3,662° |

**Au repos la cascade est plus douce** (0,036 contre 0,065). L'agent gagne quand
ça se corse : sa rugosité reste plate là où celle de la cascade double.

## Les limites de poussée

`python 10_limites.py` — poussée de 150 ms, dichotomie à 0,05 N, une force n'est
retenue que si elle tient sur 4 à 5 tirages de bruit.

| point d'application | AGENT | CASCADE | écart |
|---|---|---|---|
| sommet 210 mm | 0,70 N | 0,56 N | +25 % |
| mi-hauteur 120 mm | 1,12 N | 0,94 N | +20 % |
| essieu 0 mm | 5,30 N | 4,45 N | +19 % |

Asymétrie avant/arrière : **−6 % en arrière**, pour les deux pilotes. C'est le
modèle, pas l'agent — le CdM est décalé de 1,1 mm vers l'arrière.

**Le bras de levier domine tout** : ×7,6 entre le sommet et l'essieu.

Et surtout — mesuré sur la cascade dans `04_pousser.py` :

```
MAX_SPS 1600  →  0,204 m/s  →  0,80 N
MAX_SPS 2400  →  0,306 m/s  →  1,19 N     +49 %
MAX_SPS 2667  →  0,340 m/s  →  1,33 N     +66 %
```

**Réparer la carte vaut le double de ce que gagne le meilleur contrôleur.**

## L'entraînement

`python 07_ppo.py --pas 9000000 --env 16`

| | |
|---|---|
| durée | 16,8 min · 8 903 pas/s |
| difficulté atteinte | 1,00, à 5,1 M de pas |
| décollage | vers 1,5–1,7 M de pas |
| `ep_len_mean` final | 780 à 900 sur 1 000 |
| `clip_fraction` moyen | 3,8 % |
| `explained_variance` final | 0,950 |
| σ d'exploration | 0,223 → **0,040**, divisé par 5,5 tout seul |

9 M pas de politique = **25 h de robot simulé**, 180 M pas de physique,
accélération ×71.

## La politique

| | |
|---|---|
| acteur | 15 → 32 → 32 → 2, activation `tanh` |
| poids | **1 634** (6 885 avec le critique, jeté) |
| taille en float32 | 6,5 ko |
| coût sur ESP32 240 MHz | 1 568 MAC ≈ **13 µs**, soit 0,3 % du budget à 200 Hz |
| part linéaire | R² = 0,91 hors échantillon |

Test de capacité par régression (découpage mélangé) : `1 × 16` atteint déjà
R² = 0,997, `4 × 16` fait aussi bien que `2 × 32` pour 34 % de calcul en moins.
**Le réseau choisi est probablement surdimensionné.**

## La machine

| | |
|---|---|
| physique, un cœur, 3D | 131 000 pas/s |
| PPO, 16 environnements | 11 990 pas de politique/s → 7,2 M en 10 min |
| rendement 16 env / 1 env | ×5,6 seulement |
| `torch.set_num_threads(2)` | −18 % de temps contre les 8 par défaut |
| CPU réellement consommé | 36 % du total, soit 5,8 cœurs sur 16 |
| mémoire | 270 Mo par worker, 4,6 Go au total |

---

# Identification sur le robot réel — 9 septembre 2026, soirée

Tout ce qui suit vient de l'enregistreur embarqué à 200 Hz, sans jamais
manipuler le robot ni le faire tomber. Déplacement maximal d'un essai : 48 mm.

## Le bruit des capteurs, enfin séparé de la vibration

| grandeur | condition | mesure |
|---|---|---|
| gyro brut | robot **immobile**, moteurs muets, 6 s à 200 Hz | **0,062 °/s** |
| gyro brut | robot debout, moteurs actifs | 1,66 à 1,95 °/s |
| gyro filtré | robot immobile, 1 008 s de télémétrie | 0,145 °/s |
| accéléromètre | robot debout, moteurs actifs | **0,205 m/s²** |
| module accéléromètre | robot debout | 1,0086 g, soit 0,9 % d'écart |

**`bruit_gyro` du modèle vaut 1,088 °/s et porte l'étiquette MESURE. C'est faux
d'un facteur 17.** Les 0,062 °/s mesurés correspondent exactement à la fiche
technique du MPU-6050 sur 100 Hz de bande. Ce que mesurait le carnet n'était pas
le capteur mais la **vibration mécanique des pas-à-pas**.

La distinction n'est pas cosmétique : le bruit capteur est indépendant de tout,
la vibration est corrélée à l'activité moteur. L'agent a été entraîné avec du
bruit blanc là où la réalité lui donne une vibration structurée. Et sa
sensibilité au gyro vaut 700 pas/s² par °/s près de la verticale.

Le bruit n'est pas blanc non plus : autocorrélation 0,672 au premier retard,
énergie répartie sur toute la bande — c'est le filtre interne du MPU.

`bruit_accel` valait 0,150 m/s² en SUPPOSE ; mesuré à 0,205, soit 1,37 fois
plus. Le chiffre inclut la vibration, donc il majore le bruit propre.

## La dynamique du corps

Par balayage en fréquence, interspectres avec le signal injecté (seul signal
exogène en boucle fermée), chaque point pondéré par sa cohérence.

| | modèle (hors roues) | mesuré |
|---|---|---|
| `M·h/I` | 5,140 | **4,628 ± 0,146** |
| constante de temps | 0,1408 s | **0,1484 s** |

Vérification de structure **sans aucune masse** : le rapport entre le terme de
gravité et le gain d'actionnement doit valoir exactement g.

| hypothèse | rapport mesuré | écart à 9,81 |
|---|---|---|
| **1600 pas/tour** | 8,86 | **10 %** |
| 3200 pas/tour | 4,43 | 55 % |

**`pas_par_tour` vaut 1600.** Le paramètre DOUTEUX est résolu.

Une seule mesure ne sépare pas l'inertie de la hauteur du centre de masse. Deux
jeux collent également : inertie propre +39 %, ou centre de masse à 171 mm du
sol au lieu de 141. Il faut le pendule suspendu pour trancher.

## Le transitoire d'avance, à rejouer en simulation

Échelon de vitesse commandé, 400 pas/s pendant 2 s, enregistré à 200 Hz.

Le robot part **à reculons** — `sps` descend à −147 — avant de repartir en
avant. C'est le comportement à déphasage non minimal du balancier, et c'est
exactement le régime que la simulation doit reproduire.

Déplacement net : **37 mm** seulement. La boucle externe n'atteint que 30 % de
la vitesse commandée, à cause de `MAX_LEAD` et de la rampe de 0,4 s.

Angle atteint : +1,86° au maximum, contre +0,8° au repos.

## Le moteur, mesuré pour la première fois

Rampe de vitesse roues en l'air, 0 à 4 800 pas/s en 6 s, enregistrée à 200 Hz.

**Pas de décrochage à vide jusqu'à 4 800 pas/s**, soit 3 tours/s. La vibration
*diminue* même en montant : 0,092 °/s à 805 pas/s, 0,049 °/s à 4 009. Le plafond
`MAX_SPS = 3000` de la carte n'est donc pas fixé par le décrochage à vide. La
limite qui compte est celle **en charge**, non mesurée.

**La résonance du moteur est à 71 Hz, pas 113.**

| | moteurs en rotation | moteurs à l'arrêt, bobines alimentées |
|---|---|---|
| puissance du gyro, 60–80 Hz | **60,0 %** | 6,3 % |
| pic | 71 Hz | aucun |

Le pic n'existe que quand les moteurs tournent, et il reste **fixe** pendant que
la vitesse varie d'un facteur 9 (405 à 3 608 pas/s). Ce n'est donc pas la
fréquence des pas mais une résonance excitée par eux — celle du rotor et de la
roue contre le ressort magnétique, exactement ce que `moteur.py` modélise.

`f = (1/2π)√(k/J)` : mesurer 71 au lieu de 113 impose `k/J = 0,395` fois la
valeur du modèle. Deux lectures, non exclusives :

| lecture | conséquence |
|---|---|
| le couple de maintien est plus faible | 0,111 N·m au lieu de 0,280 |
| les roues sont plus lourdes | `masse_roue` = 86 g au lieu de 30 |

`masse_roue` porte l'étiquette ESTIME. Une roue plastique de 65 × 26 mm avec
moyeu à 86 g est parfaitement plausible — l'estimation à 30 g était basse.
La vérité est probablement entre les deux, et une balance de cuisine
trancherait en dix secondes.

**C'est le premier chiffre mesuré sur l'actionneur**, celui dont dépend tout le
comportement que `moteur.py` doit reproduire, et qui n'a jamais servi à
entraîner.

Autre résonance, distincte : ~21 Hz quand le robot est debout au sol, ~70 Hz
quand il est tenu en main. Modes du châssis imprimé, sans lien avec le moteur.

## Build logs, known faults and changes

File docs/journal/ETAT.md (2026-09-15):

# Où on en est

> **À lire en premier à chaque reprise. À mettre à jour en dernier avant de couper.**
> Dernière mise à jour : **9 septembre 2026**.

## En une phrase

Le robot balancier est modélisé dans MuJoCo depuis la CAO, la cascade du
firmware y est portée comme témoin, et une politique PPO de 1 634 poids la bat
sur tous les critères sous contrainte. **La politique est exportée en C et
validée à 2×10⁻⁷ près, mais elle n'a pas encore tourné sur la carte.**

## La prochaine étape

**Le témoin cascade, 45 secondes.** C'est la seule mesure qui manque pour
pouvoir écrire un chiffre au lieu d'une impression. Le nouvel agent a volé
76 s sur le robot avec 536 pas/s d'écart-type de commande, contre 893 pour
l'ancien. Mais la cascade n'a pas été relancée juste après, donc le rapport
agent contre cascade sur matériel reste inconnu.

Puis le Vref de l'A4988, qui tranche entre couple faible et roues lourdes.

## 10 et 11 septembre : la direction, le pupitre, la publication

### La direction fonctionne enfin

C'était la limite ouverte depuis le début du projet : les deux broches STEP
partageaient un timer, donc les deux roues recevaient exactement les mêmes
impulsions et le robot ne pouvait pas tourner.

Le timer bat désormais à **cadence fixe, 25 kHz**, et chaque moteur porte son
propre accumulateur en virgule fixe 16.16. Quand il déborde, cette roue-là émet
un pas. C'est un Bresenham : deux vitesses indépendantes sur un seul timer,
erreur de phase bornée à un pas.

Effet de bord : la demi-période ne se reprogramme plus jamais. On avait mesuré
186 reprogrammations par seconde en cherchant la cause d'un plantage. Il n'y en
a plus aucune.

Nouvelle commande `#<valeur>`, différence de vitesse entre les roues, positif =
virage à droite. Plafond 2000, remise à zéro à chaque désarmement.

### Deux bugs trouvés par Matthieu en pilotant

**La consigne accumulait une dette.** La boucle externe intégrait la vitesse
demandée en une cible de position ; quand le robot ne suivait pas, la cible
filait devant et il restait penché à rembourser. Sa formulation : « s'il n'a
pas fait sa consigne il tente à l'infini ». Corrigé par deux régimes séparés :
consigne non nulle, la cible de position SUIT la position réelle et aucune
dette ne s'accumule ; consigne nulle, elle se fige à l'instant du relâchement.

**Les boutons du pupitre étaient sourds.** STOP attendait derrière des dizaines
de commandes de joystick. Corrigé : STOP jette la file et écrit immédiatement,
une consigne écrase la précédente du même type, et la file est poussée toutes
les 20 ms.

### Le pupitre

`tools/pupitre.py`. Joystick 2D, échelles de ×0,5 à ×3, ressort
ou maintien au relâchement, bouton de calage, et l'état en direct dont la
verticale et la correction. Les boutons de pilote s'allument **d'après la
télémétrie**, pas d'après le dernier clic : un ordre perdu se voit.

Il ne touche pas au port série. Il lit `logs/robot.log` et dépose ses commandes
dans `tools/cmd.txt`, comme tout le reste du projet.

### Un piège de plus, à retenir

**L'auto-trim ne tourne pas en mode agent.** Il vit dans la boucle externe, et
celle-ci est désactivée quand l'agent pilote, volontairement, pour que la
verticale ne bouge pas sous ses pieds. Mesuré : en cascade l'offset dérive de
2,09° en 65 s ; en agent il ne bouge pas d'un centième.

**Conséquence pratique : armer la cascade une minute AVANT de passer à
l'agent**, pour que l'auto-trim trouve le vrai point d'équilibre. Sinon l'agent
part avec l'offset qu'on lui a laissé, se penche, et dérive.

## La publication

Vidéo : `rendus/v3_moteur_fidele/post_sim_vs_real.mp4`, 1080x1920, 45 s, muette.
Une seconde de couverture fixe (c'est elle que LinkedIn prend comme vignette),
robot réel plein cadre, simulation en médaillon étiqueté, mosaïque verticale
centrée, signature. Construite par `montage_post.py`, avec `montage_reel.py` et
`19_mosaique_verticale.py`.

Texte : 2 609 caractères, en anglais (hors dépôt).

**Les chiffres du post, revérifiés sur `logs/robot.log.old`** — le journal a
pivoté le 10 à 19 h 12, donc tout le 9 septembre est dans `.old`, et une
analyse faite sur `robot.log` seul donne des chiffres faux :

| | simulation corrigée | robot réel |
|---|---|---|
| erreur d'angle | 1,743° | 1,572° |
| commande | 873 pas/s | 878 pas/s |

Soit 1 % sur la commande et environ 10 % sur l'inclinaison.

**Une objection de Matthieu, tranchée par la mesure.** Il a demandé si le
tremblement de l'ancien agent ne venait pas d'un mauvais calage plutôt que du
modèle de moteur. Non, et pour deux raisons indépendantes : l'offset venait de
l'auto-trim de la cascade qui avait convergé juste avant, et il n'a pas bougé
d'un centième pendant le vol ; et la simulation corrigée, qui n'a aucune erreur
de calage possible, reproduit le même défaut.

## La boucle est bouclée

C'est le résultat de la soirée du 9 septembre. Le même agent, entraîné sur
l'actionneur en vitesse, jugé dans la nouvelle simulation et sur le vrai robot :

| | simulation fidèle | robot réel |
|---|---|---|
| erreur d'angle, écart-type | 1,743° | 1,621° |
| commande, écart-type | 873 pas/s | 893 pas/s |

**2 % d'écart sur la commande, 8 % sur l'angle.** La simulation reproduit
maintenant le défaut observé sur le matériel, et elle n'a jamais été ajustée sur
cette observation : les seules choses recalées sont la résonance à 71 Hz et le
bruit des capteurs, mesurés séparément.

Avant, la simulation disait que l'agent battait la cascade partout. Le robot
disait qu'il tremblait dix fois plus. Les deux disent maintenant la même chose.

## Le nouvel agent

Réentraîné avec `moteur.py`, 9 M pas en 15,7 min, difficulté 0,85.
Tous les agents jugés sur le moteur fidèle, robot calme :

| | ancien | **nouveau** | cascade |
|---|---|---|---|
| erreur d'angle, écart-type | 1,743° | **0,106°** | 0,185° |
| commande, écart-type | 873 pas/s | **47 pas/s** | 86 pas/s |
| dérive de position | 55 mm | 12 mm | 13 mm |
| récompense | 2 451 | **3 777** | 3 833 |
| survie à difficulté 1,0 | 25 % | **42 %** | 33 % |

Erreur divisée par 16, commande par 19. Il passe devant la cascade.

Réserve : le compteur d'inversions monte à 65/s contre 13. Ce n'est pas une
régression — le nouvel agent fait de petites corrections qui traversent zéro
souvent, l'ancien faisait de grandes embardées lentes. C'est l'amplitude qui
compte.

## Ce qui a été construit ce soir

**Le plantage** : la transaction I2C bloquait la boucle de commande. Déplacée
dans une tâche dédiée sur le cœur 0, non abonnée au chien de garde. 252 s de
secousse à plein régime sans un plantage, contre deux en 106 s. Effet de bord :
les échecs I2C au repos sont passés de 1,01/s à 0,00/s.

**L'identification sans manipulation.** Enregistreur 200 Hz dont le vidage ne
fait plus tomber le robot. Balayage sur l'accélération (48 mm de déplacement)
puis sur la consigne d'angle (45 mm), interspectres avec le signal injecté.

**Les mesures** : `pas_par_tour` = 1600 (était DOUTEUX), `bruit_gyro` divisé
par 17, `bruit_accel` mesuré, résonance moteur à 71 Hz au lieu de 113 supposés.
Il reste **2 paramètres non établis sur 24**, contre 4 sur 22 le matin.

**Le modèle** : `moteur.py` branché pour la première fois, résonance recalée,
masse de roue randomisée entre 30 et 110 g avec le couple qui redonne les
71 Hz. Pas de physique relâché de 10 kHz à 2 kHz après vérification :
l'entraînement passe de 34 à 15,7 min.

**La récompense** : pénalité d'inversion de 0,15 à 0,35, et surtout un terme
neuf sur **l'angle de charge du moteur** — ce que le moteur subit, pas ce que
la commande a l'air de valoir.

## Les rendus

Dans `rendus/v3_moteur_fidele/`, tous sur le moteur fidèle. `film.py` le prend
désormais par défaut : filmer un agent sur l'actionneur en vitesse revient à le
filmer sur un robot qui n'existe pas.

| | |
|---|---|
| `comparaison_large.mp4` | ancien contre nouveau, le tremblement se voit |
| `duel_large.mp4` | nouvel agent contre cascade |
| `demo_large.mp4` | le nouvel agent seul |
| `progression_large.mp4` | les 16 jalons, 152 s |
| `mosaique_large.mp4` | les 16 jalons simultanés |

### Le scénario était devenu faux

Matthieu a repéré dans le journal de rendu que **l'agent de 9 M tombait**. Ce
n'était pas un artefact : le scénario poussait à 0,45 puis 0,64 N, valeurs
calibrées sur l'actionneur en vitesse. Le moteur fidèle divise la poussée
encaissée par près de deux, exactement comme `moteur.py` l'annonçait avant
qu'on s'en serve.

**Limites mesurées** (`17_pousser_agents.py`, poussée isolée de 150 ms à 21 cm,
6 graines sur 8) :

| | actionneur vitesse | **moteur fidèle** |
|---|---|---|
| cascade | 0,56 N | **0,47 N** |
| ancien agent | 0,70 N | **0,38 N** |
| nouvel agent | — | **0,53 N** |

L'ancien agent encaisse donc **moins que la cascade** sur le vrai moteur.

**Et un résultat négatif qu'il ne faut pas maquiller** : l'avantage de 13 % du
nouvel agent en poussée isolée ne survit pas à un enchaînement. Dans le
scénario, à 0,55 N les deux tombent, à 0,50 les deux tiennent — il n'existe pas
de fenêtre qui les sépare. On a donc laissé le scénario **sous la limite des
deux** plutôt que de fabriquer une différence non robuste dans une vidéo
destinée à être publiée. Ce qui s'y voit est la vraie différence : le
tremblement.

Scénario figé : 0,28 N à 1,8 s et 4,0 s, 0,50 N à 16 s. Vérifié : le nouvel
agent tient, la cascade tient, l'ancien agent tombe à 4,8 s.

La progression raconte bien l'apprentissage : chute à 0,8 s jusqu'à 1,3 M de
pas, puis 2,3 s, 4,8 s, 15,6 s, et les deux derniers jalons tiennent le
scénario entier.

## Bloqué sur le matériel — 9 septembre, 23 h 15

Le vol du nouvel agent **n'a pas pu être fait**. Le firmware est téléversé, le
test de signe est passé (portage vérifié à 0,2 % contre gcc), il ne manque que
l'essai.

**Symptômes** : une roue ne tourne plus et les moteurs sifflent à l'arrêt. Un
élément 18650 sur quatre est mort, les trois autres sont mal chargés.

> **Correction du 15 septembre 2026.** Il n'y a pas de problème de batterie :
> elles étaient déchargées. Une fois rechargées, le robot a retrouvé son
> comportement et le nouvel agent a volé. Les points 1 et 5 de la liste
> « À faire » ci-dessous sont donc caducs.

**La cascade a servi de témoin, et c'est ce qui a sauvé la mesure.** Lancée
avant l'agent :

| | référence 21 h 33 | après recharge partielle |
|---|---|---|
| erreur d'angle, écart-type | 0,155° | **1,851°** |
| commande, écart-type | 158 pas/s | **1 035 pas/s** |

Douze fois pire, et tenue seulement 11 s. Sans ce témoin, on aurait mesuré
l'agent, vu un désastre et conclu que le réentraînement avait raté.

**Diagnostic le plus probable** : sous-tension. Les bobines restent alimentées
à l'arrêt ; quand la tension chute, le découpage du driver n'arrive plus à
réguler et siffle. Et comme les deux moteurs reçoivent les mêmes impulsions
d'un seul timer, celui qui a le plus de frottement décroche le premier — ce
n'est pas une roue en panne, c'est une roue en limite.

## À faire au retour du robot, dans l'ordre

1. **Refaire le pack.** Quatre cellules identiques choisies pour le courant
   (Samsung 25R, Sony VTC6, Molicel P26A), pas pour la capacité. Ne pas mélanger
   une neuve avec trois usées.

2. **Mesurer le Vref de l'A4988.** Hypothèse chiffrée : la résonance à 71 Hz
   implique un couple de 0,111 N·m si les roues font 30 g. Or un 17HS3401 réglé
   à 0,5 A donnerait **0,108**, à 3 % près. Matthieu n'a jamais touché le
   potentiomètre — or ces cartes sortent d'usine à un réglage arbitraire, souvent
   bas. Si le Vref lit ~0,4 V avec des shunts `R100`, tout se recoupe, et monter
   à 1 A rendrait **le double de couple**. Si le Vref est correct, alors ce sont
   les roues qui font 110 g. Cette mesure tranche l'ambiguïté mieux qu'une
   balance.

3. **Commande `5`, roues en l'air, 20 s.** La résonance vaut la racine du couple
   disponible. Retour à 71 Hz = moteur et driver sains, c'était l'alimentation.

4. **Puis le vol.** Cascade témoin, puis agent. La prédiction à confirmer :
   **écart-type de commande ~47 pas/s**, contre 873 pour l'ancien agent et 86
   pour la cascade.

5. **Un pont diviseur vers une entrée analogique.** Il n'existe aucune lecture
   de tension sur ce robot, et c'est pour ça qu'un élément est mort sans
   prévenir. La résonance du moteur ne le dit pas : l'A4988 régule le courant,
   donc le couple reste identique jusqu'à ce que la régulation lâche — mesuré
   71,0 Hz à 21 h 56 et 71,5 Hz à 22 h 40 avec un élément déjà mort.

## Pistes matérielles notées

`TMC2209` en remplacement de l'A4988 : courant réglé en logiciel, silencieux,
**détection de décrochage intégrée** — exactement le signal qu'on a cherché à
mesurer indirectement toute la soirée. 6 à 8 € pièce, le meilleur euro à
dépenser sur ce robot.

Encodeurs : `stepCount` compte les pas **commandés**, jamais les pas faits.
L'AS5600 a une adresse I2C fixe donc on ne peut pas en mettre deux ; préférer
AS5047P ou MT6701 en SPI, ou de la quadrature comptée en matériel. Matthieu a
des AS5600 sous la main, réservés à un autre projet.

`RP2350` : ses blocs PIO génèrent les impulsions de pas en matériel, ce qui
lèverait la contrainte du timer unique qui empêche aujourd'hui la direction, et
aurait rendu impossible le plantage corrigé ce soir.

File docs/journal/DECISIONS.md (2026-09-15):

# Décisions de conception

Chaque choix, sa raison, et ce qu'il faudrait pour le remettre en cause.
Objectif : ne pas re-débattre de la même chose dans trois semaines.

---

## Le modèle

**Des primitives, pas les STL, pour la physique.** Ce qui compte pour la
dynamique, ce sont les masses et les inerties, pas la forme. Les maillages
portent la masse — MuJoCo en déduit l'inertie sur la vraie géométrie — mais le
contact au sol reste un **cylindre**, plus juste qu'un maillage pour un pneu et
100 fois plus rapide.

Les maillages portent aussi la collision, mais MuJoCo les **convexifie** : le
robot tombe sur son enveloppe, pas sur son cadre ajouré. Faux dans le détail,
sans conséquence — ça ne sert qu'après une chute. Coût mesuré : −24 % de vitesse.

**Modèle 3D par défaut, plan disponible.** L'articulation libre coûte 11 % et
apporte le lacet, sans lequel il n'y a pas de direction. Le modèle plan reste
utilisé par `02_identifier.py`, où mesurer un mode propre est un problème à un
seul degré de liberté.

**Lire l'état par les capteurs, jamais par `qpos`.** Deux raisons : les scripts
deviennent indépendants du choix plan/3D, et surtout on se rend **incapable de
tricher**. L'information privilégiée est la première cause de transfert raté.

**Le pas-à-pas modélisé en actionneur de vitesse, par défaut.** Le modèle fidèle
(`moteur.py`, ressort magnétique `C = C₀·sin(50·Δθ)`) est plus juste — il génère
la vibration mécanique du bon ordre, et divise par deux la poussée encaissée —
mais coûte 7× plus cher (pas de temps 5× plus fin, résonance à 113 Hz).
**À remettre en cause :** il devrait servir au moins comme variante de
randomisation avant tout transfert.

---

## L'environnement d'apprentissage

**Politique à 100 Hz, intégrateur à 200 Hz.** À 200 Hz un épisode fait 2 000
décisions et l'attribution du mérite devient trop bruitée. Sur l'ESP32, la boucle
reste à 200 Hz et la politique se contente d'un tick sur deux.

**Action = accélération de roue, en pas/s².** Exactement la sortie de la boucle
interne du firmware. L'agent devient un **remplaçant direct** de la cascade, au
même point d'insertion. Deux valeurs et non une, parce que le modèle 3D permet
de tourner.

**Observation : 15 nombres, tous mesurables sur le robot.** Aucune vérité
terrain. L'angle vient du même filtre complémentaire que le firmware, appliqué à
des capteurs **bruités**, avec un biais tiré à chaque épisode.

**Récompense : primes en cloche, pénalités sur les différences.** Voir
`PIEGES.md` n° 1 — c'est la seule forme qui garantit une récompense positive
tant que le robot est debout.

**Lissage par la dérivée seconde, pas la première.** `a(t) − 2a(t−1) + a(t−2)`
vaut zéro pour une rampe à pente constante — une grosse correction soutenue ne
coûte rien — et explose dès que la commande s'inverse. Mesuré : la première
différence sépare correction et tremblement d'un facteur 192, la seconde d'un
facteur 4 125. Dosage 0,02 / 0,15.

Conséquence obligatoire : **`a(t−2)` doit être dans l'observation**, sinon on
pénalise quelque chose que la politique ne peut pas contrôler.

**Pas de `VecNormalize`.** L'observation est déjà mise à l'échelle à la main par
des grandeurs physiques connues. La politique est donc **autonome** : pour la
porter sur l'ESP32 il n'y a que des poids à copier, aucune statistique à
transporter ni à tenir à jour.

**Curriculum tiré au hasard entre 0 et le maximum courant**, jamais une rampe —
une rampe fait oublier le cas facile. Le maximum monte **au mérite** (80 % de
survie sur 50 épisodes), et le tampon se vide après chaque montée.

**Poussées : on tire l'impulsion angulaire, puis on répartit.** Ce qui bascule un
pendule, ce n'est ni la force ni la hauteur prises séparément, c'est
`couple × durée`. On tire donc `impulsion ∈ [0 ; 0,045·k] N·m·s`, une hauteur
dans [0,08 ; 0,22] m, une durée dans [0,05 ; 0,20] s, et la force en découle.

---

## L'algorithme

**PPO plutôt que SAC.** La simulation produit 9 000 pas/s : les échantillons ne
coûtent rien, et PPO est plus stable et se parallélise mieux. SAC deviendrait le
bon choix pour apprendre **sur le vrai robot**, où chaque chute coûte cher.

**Réseau 2 × 32, `tanh`.** Choisi d'abord par la contrainte de déploiement :
1 634 poids, 13 µs sur ESP32, 0,3 % du budget. L'architecture standard de la
locomotion (512-256-128) demanderait 691 ko de poids — elle ne tient pas dans les
520 ko de RAM.

`tanh` plutôt que ReLU : lisse (pas de coude qui produirait des à-coups) et
**bornée** — une entrée hors domaine sature au lieu de traverser. Le contre-
argument du gradient qui s'évanouit ne mord qu'à partir de dix couches.

**À remettre en cause :** la mesure de capacité montre que `4 × 16` fait aussi
bien pour 34 % de calcul en moins, et que `1 × 16` atteint déjà R² = 0,997.
Le réseau est probablement surdimensionné. Le choix vient de la convention du
domaine, pas d'une mesure.

**`gamma = 0,99` à 100 Hz** → horizon de 100 pas = 1 s, l'ordre de grandeur du
retour à l'équilibre. Le défaut des bibliothèques est calibré pour 30–50 Hz ; à
200 Hz il rendrait l'agent myope.

**`log_std_init = -1.5`.** Voir `PIEGES.md` n° 2.

---

## L'outillage

**Le rendu est séparé de l'entraînement.** L'entraînement produit des poids, le
rendu produit des images. On peut refaire toutes les vidéos — format, habillage,
scénario, caméra — sans jamais réentraîner.

**Jalons placés d'après la courbe, pas en progression géométrique.** Un
espacement uniforme gaspillait huit jalons sur douze avant le décollage. Les 16
retenus sont resserrés entre 1,3 M et 4 M, là où le comportement change.

**Scénario de film écrit et identique pour tous les pilotes et tous les jalons.**
C'est ce qui rend les vidéos comparables entre elles. Les forces sont calibrées
sur les limites mesurées : la dernière poussée vaut 0,64 N, entre les 0,56 N de
la cascade et les 0,70 N de l'agent — la seule fenêtre où le duel montre quelque
chose.

**Pupitre Tkinter séparé** plutôt que le clavier du viewer. Voir `PIEGES.md` n° 9.

**Boîte noire des chutes.** Une chute ne se diagnostique pas à l'instant où elle
arrive : c'est la seconde d'avant qui contient la cause. `chutes/*.csv` garde
1,5 s d'historique à 100 Hz.

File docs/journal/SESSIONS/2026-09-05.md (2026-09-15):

# 5 septembre 2026 — première session

De rien à un agent entraîné. Une journée.

## Ce qui a été fait, dans l'ordre

**1. Lecture du carnet du balancier**, et trois erreurs relevées dedans :

- les roues font **65 mm**, pas 90 comme supposé → toutes les conversions
  pas↔mm du carnet sont surévaluées d'un facteur 1,38 ;
- `L = 13,6 cm` n'est **pas la hauteur du centre de masse** — la formule
  `g/(2πf)²` donne la longueur du pendule *ponctuel* équivalent, toujours plus
  grande. Le vrai CdM est vers 74 mm ;
- le **1,35 Hz ne mesure rien de mécanique** : oscillation en boucle fermée,
  donc fonction des gains. Matthieu l'avait déjà écrit dans son post LinkedIn,
  plus précisément que dans le carnet.

**2. Modèle MuJoCo**, d'abord à la main, puis **reconstruit depuis l'export
d'assemblage SolidWorks**. L'axe des roues a été localisé en tranchant le
maillage moteur pour y trouver l'arbre de Ø5,00 mm. La géométrie ne se suppose
plus, elle se lit.

**3. Portage du firmware** (`firmware.py`) comme témoin. Il tient debout avec
les gains du carnet, sans retouche — première validation sérieuse du modèle.

**4. Modèle fidèle du pas-à-pas** (`moteur.py`). Un pas-à-pas n'est ni une
source de vitesse ni une source de couple : c'est un **ressort magnétique**.
Il génère 5,45 °/s de vibration mécanique, du bon ordre que les 1,08–3,48 °/s
du carnet — le modèle en vitesse n'en produit aucune.

**5. Quantification de l'incertitude** (`incertitude.py`). Résultat inattendu :
les masses estimées suffisent, la fourchette sur la prédiction d'établi n'est
que de −4 / +3 %. C'est ce qui a débloqué le passage au RL sans attendre les
mesures.

**6. Passage en 3D**, articulation libre, deux roues indépendantes, pour
pouvoir commander la direction.

**7. Environnement, entraînement, duel.** Trois runs successifs, chacun
débloquant un bug (voir `PIEGES.md`). Le troisième : 9 M pas, 16,8 min,
difficulté 1,00.

**8. Outillage de rendu** et sept vidéos, dont une mosaïque 4×4 des 16 jalons
jouant le même scénario en simultané.

## Ce que Matthieu a trouvé lui-même

Trois bugs, tous repérés en pilotant, aucun visible dans une courbe :

- « il est censé avoir 2 boucles » → le mode G activé silencieusement par
  `'' in 'GK'` ;
- « quand j'appuie sur pousser arrière, ça dépend de l'orientation » → la force
  appliquée dans le repère du monde, qui rendait aussi l'entraînement 36 % plus
  faible qu'annoncé ;
- « il encaisse la poussée, puis fait un truc pour tomber » → l'observation sans
  borne, hors domaine d'entraînement.

Le troisième s'est révélé être **le même problème que `MAX_LEAD`** dans son
firmware, découvert indépendamment des deux côtés.

## Corrections que j'ai annoncées sans les vérifier

Deux fois, un motif de remplacement n'avait pas matché et j'ai affirmé qu'une
correction était en place alors qu'elle ne l'était pas — la collision du châssis,
et l'activation d'un patch. **Toujours relire le fichier produit, pas le script
qui le produit.**

## Livrables

```
23 fichiers Python et Markdown
16 jalons d'entraînement + l'agent final
 7 vidéos dans rendus/v2_final/
10 chutes enregistrées dans chutes/
 1 brouillon de post LinkedIn, NON PUBLIÉ
 3 documents publiés en artifacts (MuJoCo, RL, et ce journal)
```

## Décision de fin de session

**Ne pas publier le post encore.** Le transfert sur l'ESP32 est à 2–3 h de
travail, et il change complètement la catégorie du projet : « j'ai entraîné un
agent en simulation » est banal, « la politique tourne sur mon ESP32 » ne l'est
pas.

**Lundi : export de la politique en C.**

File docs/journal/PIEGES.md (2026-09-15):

# Catalogue des pièges

Chaque entrée : le **symptôme** tel qu'il apparaît, la **cause**, le **coût**,
et la **règle** qui en sort. C'est la partie la plus réutilisable du projet —
les bugs se transposent à l'humanoïde, pas le réseau.

---

## 1. Une récompense négative apprend au robot à se suicider

**Symptôme.** Après 600 000 pas, `ep_len_mean` plafonne à 91 sur 1 000. Le robot
tombe en 0,9 s et n'en bouge plus. La courbe est parfaitement plate.

**Cause.** Je pénalisais l'écart de vitesse en quadratique, sans borne :

```
sps      pénalité vitesse   prime survie   TOTAL
   0            −0,00            1,00       1,00
 800            −0,93            1,00       0,07
1200            −2,08            1,00      −1,08   ← négatif
```

Or un pendule inversé **doit** lancer ses roues pour se rattraper. Je pénalisais
exactement ce qui le sauve, plus fort que le fait de rester debout. Dès qu'un
pas rapporte une récompense négative, **terminer l'épisode devient optimal**.

**Coût.** 600 000 pas d'entraînement, et un diagnostic erroné en cours de route
(« il n'apprend pas » alors qu'il apprenait très bien la mauvaise chose).

> **Règle.** Tant que le robot est debout, la récompense d'un pas doit rester
> **positive**. Utiliser des termes en cloche `exp(−(x/σ)²)`, bornés dans [0, 1],
> qui ne peuvent jamais écraser la prime de survie.

---

## 2. `log_std_init = 0` : un bruit d'exploration pleine échelle

**Symptôme.** 1,8 million de pas de plateau à `ep_len_mean ≈ 85` avant que quoi
que ce soit ne décolle.

**Cause.** Le défaut de SB3 donne σ = 1,0 sur une action qui vaut ±25 000 pas/s².
L'exploration était un bruit blanc à pleine échelle : impossible d'équilibrer
par hasard, donc aucune trajectoire de départ à exploiter.

**Correction.** `log_std_init = -1.5`, soit σ = 0,22. Le décollage passe de
1,8 M à 1,5 M de pas et devient franc.

> **Règle.** Le bruit d'exploration se règle **par rapport à l'échelle de
> l'action**, pas par rapport au défaut de la bibliothèque.

---

## 3. Le curriculum qui monte à chaque pas

**Symptôme.** La difficulté passe de 0,15 à 1,00 en 300 millisecondes, à la fin
de l'entraînement. L'agent n'a jamais vu les niveaux intermédiaires.

**Cause.** Une fenêtre glissante de 50 épisodes. Une fois le seuil de survie
franchi, elle **reste** au-dessus, donc la condition se déclenche à chaque pas.

**Correction.** Vider le tampon après chaque montée : chaque palier doit être
re-mérité sur des épisodes neufs.

> **Règle.** Un curriculum monte **au mérite**, et le mérite se reconstate sur
> des données fraîches après chaque changement.

---

## 4. La poussée appliquée dans le repère du monde

**Symptôme.** Même commande « pousser en arrière », le robot part parfois en
avant, parfois en arrière. Repéré par Matthieu en pilotant.

**Cause.** `mj_applyFT` recevait une force le long de **x du monde**. Le robot
démarre avec un cap tiré au hasard sur ±180° — la direction de poussée était donc
arbitraire par rapport à lui.

**Conséquence bien plus grave.** Les poussées **d'entraînement** avaient le même
défaut. La composante utile valait `2·cos(θ)` avec θ uniforme, soit une moyenne
de 1,27 N au lieu de 2,00 — **36 % de moins qu'annoncé**, et parfois presque
rien quand le robot était de profil.

**Correction.** Force le long de l'avant du robot, lacet seulement :

```python
lac = radians(etat.lacet(m, d))
avant = [cos(lac), sin(lac), 0]
```

Après correction, l'avantage de l'agent sur la cascade en rejet de perturbation
passe de **+8 % à +25 %**.

> **Règle.** Toute grandeur directionnelle — force, vitesse, angle — doit être
> exprimée dans un repère **explicitement choisi**. Le même piège a frappé deux
> fois : le tangage était aussi mesuré dans le repère du monde, et se répartissait
> entre tangage et roulis dès que le robot avait tourné.

---

## 5. Une observation sans borne, et le réseau se jette par terre

**Symptôme.** Le robot encaisse une poussée, puis « fait un truc » et tombe
quelques secondes plus tard. Repéré par Matthieu.

**Cause.** L'écart de position entrait dans l'observation sans borne. Il n'avait
**jamais dépassé 1,10** pendant l'entraînement :

```
écart 0,5 m  →  obs = 2,50   il tient
écart 1,0 m  →  obs = 5,00   CHUTE en 0,64 s
écart 2,0 m  →  obs = 10,0   CHUTE en 0,42 s
```

Un réseau n'extrapole pas. Devant une valeur inconnue il produit une accélération
aberrante — ici, pour « rentrer » — et se jette par terre.

**Correction.** Saturer l'écart à ±1,75 dans l'observation, plus un `clip(−6, 6)`
général sur toutes les entrées. **Le même agent, sans réentraînement, tient
ensuite jusqu'à 10 m d'écart.**

**Le point remarquable.** C'est exactement le problème que `MAX_LEAD` résout dans
le firmware du robot réel — la dette de position qui file et se rembourse d'un
coup. Découvert indépendamment des deux côtés.

> **Règle.** **Borner toutes les observations.** C'est gratuit dans le domaine
> normal et ça évite la catastrophe au-delà. Vérifier après entraînement
> l'amplitude réellement vue de chaque entrée.

---

## 6. `'' in 'GK'` vaut `True`

**Symptôme.** Dans le bac à sable, le robot dérive comme s'il n'avait plus de
boucle externe. Repéré par Matthieu : « il est censé avoir 2 boucles ».

**Cause.** Le gestionnaire de touches faisait `c = chr(code) if 32 <= code < 127
else ''`, puis `elif c in 'GK'`. En Python, **la chaîne vide est incluse dans
toute chaîne**. Une touche non imprimable — `Ctrl`, `Maj`, une flèche — basculait
donc silencieusement en mode G et coupait la boucle externe.

Un appui sur `Ctrl` pour tirer à la souris suffisait.

> **Règle.** Tester l'appartenance avec un **tuple**, jamais une chaîne.
> Et rejeter les codes non imprimables en amont.

---

## 7. `mj_resetData` remet `d.time` à zéro

**Symptôme.** Après un « redresser », le robot repart comme si une force
permanente le poussait. Puis, plus tard : chute à 1 N, une force qu'il encaisse
largement.

**Cause.** Les fins de poussée étaient stockées en **date absolue**
(`fin = d.time + 0.15`). Une remise à zéro du temps — par `mj_resetData`, ou par
ma prolongation d'épisode toutes les 10 s — rendait la condition
`d.time < fin_poussee` à nouveau vraie, et **réappliquait la force pendant dix
secondes**.

> **Règle.** Ne jamais mémoriser une échéance en date absolue quand l'horloge
> peut être remise à zéro. Annuler explicitement les événements en cours lors
> d'une réinitialisation.

---

## 8. Le viewer passif n'applique pas la perturbation souris

**Symptôme.** Ctrl + glisser dans la fenêtre MuJoCo ne produit aucune force.

**Cause.** `launch_passive` **expose** `viewer.perturb` mais ne l'applique
jamais — c'est au script d'appeler `mujoco.mjv_applyPerturbForce`.

Et attention : c'est un **ressort** vers une position de référence, pas une
impulsion. Si `perturb.active` reste armé, il tire indéfiniment.

---

## 9. Le viewer s'approprie presque toutes les touches

**Symptôme.** Un appui sur `Z` déclenche l'action voulue **et** une bascule
d'affichage MuJoCo.

**Cause.** Le viewer réserve `Z` lumière, `Q` caméras, `S` échelle d'inertie,
`D` point de sélection, `H` enveloppe convexe, `P` découpe des contacts, `C`
points de contact, `T` transparence, `M` centre de masse… Le callback utilisateur
reçoit la touche **en plus**, sans pouvoir l'intercepter.

**Correction.** Interface séparée — un pupitre Tkinter (`09_piloter.py`).

---

## 10. Pièges d'outillage, sans conséquence mais coûteux en temps

- **MuJoCo 3.x n'a plus le drapeau `sensornoise`.** Le bruit s'ajoute côté Python.
- **Sous Windows, `SubprocVecEnv` relance l'interpréteur** : la classe
  d'environnement doit vivre dans un module importable, et un nom de module ne
  peut pas commencer par un chiffre. D'où `balancier_env.py` distinct de
  `06_env.py`.
- **`offheight` du XML limite le rendu hors-écran.** Rendre en 1080×1350 exige
  de l'augmenter.
- **Annoncer une correction sans la vérifier.** C'est arrivé deux fois : un motif
  de remplacement n'avait pas matché, et j'ai affirmé que la collision du châssis
  était activée alors qu'elle ne l'était pas. **Toujours relire le fichier
  produit, pas le script qui le produit.**

---

## 11. Une politique exportée porte un état : la tester hors boucle la fait dériver

**Symptôme.** Test de signe roues en l'air, robot immobile à 0,20° : la sortie
affichée monte à chaque impression — 17 489, puis 17 645, puis 17 739 pas/s².
La table de référence donne +444 à cet angle.

**Cause.** `politique_accel()` écrit `pol_a_prec` et `pol_a_prec2`, qui sont
quatre des quinze entrées du réseau. Mon bloc de test les laissait s'accumuler
d'un appel au suivant. Pire : le test ment au réseau en lui passant `sps = 0` et
`pas = 0` quoi qu'il commande. Il voit donc une roue qui ne répond jamais et
pousse de plus en plus fort — un enroulement d'intégrateur, mais dans les poids.

**Coût.** Le test aurait été lu comme un signe correct avec une amplitude
aberrante, ou comme une politique instable. Aucune des deux lectures n'aurait
été vraie.

**Règle.** Un appel de politique hors de sa boucle fermée doit être encadré de
`politique_reset()`. Et toute table de référence doit dire depuis quel état elle
a été calculée.

---

## 12. Le moniteur série ne survit pas toujours au téléversement

**Symptôme.** Après un flash réussi, `logs/robot.log` s'arrête douze jours plus
tôt sur `--- aucun port detecte, attente ---`. Le robot semble muet.

**Cause.** Le processus du moniteur avait disparu. Le script lâche bien le port
quand `esptool` tourne, mais il n'est pas immunisé contre sa propre mort.

**Règle.** Avant de conclure quoi que ce soit d'un log muet, vérifier que le
moniteur est vivant, et regarder l'horodatage de la dernière ligne, pas son
contenu.

---

## 13. Six lignes ne font pas une distribution

**Symptôme.** `Lus` lu à 2 060 µs après le patch contre 1 203 µs avant : j'ai
annoncé une régression de temps de boucle de +70 %.

**Cause.** J'ai comparé six lignes de queue à six lignes de queue. Sur les
20 875 lignes de l'ancien log au même état, la distribution est déjà bimodale :
52 % sous 1 500 µs, 48 % au-dessus. Rien n'avait changé.

**Règle.** Une comparaison avant/après se fait sur les deux distributions
complètes, à état égal — même mode, même `hz`. C'est la même règle que pour le
1,35 Hz du carnet : un chiffre isolé ne mesure rien.

---

## 14. Le plantage n'était pas dans le code qu'on venait d'écrire

**Symptôme.** La carte redémarre après quelques dizaines de secondes, toujours
pendant que l'agent pilote. Chien de garde de tâche sur `loopTask`, puis défaut
d'interruption sur le cœur 0.

**Ce que j'ai cru.** Que l'agent, en commandant des inversions à pleine
amplitude, martelait le pilote de timer de pas. L'hypothèse était cohérente : le
firmware documentait déjà une panne de cette famille.

**Ce que la mesure a dit.** Une boîte noire en RAM RTC, qui survit au
redémarrage et enregistre l'étape de boucle en cours. Quatre plantages, quatre
fois `bloque a l etape 3 (transaction I2C)` — dont deux en mode secousse, qui
ne lit pas l'angle et ne fait tourner aucune boucle, et un en cascade seule.
Et les compteurs ont tué l'hypothèse du timer : la cascade le reprogramme déjà
**186 fois par seconde**, le maximum possible à 200 Hz, tandis que la secousse
le reprogramme **0,07 fois par seconde** et plante quand même.

**Coût.** Deux heures à instrumenter la mauvaise piste, et une affirmation
fausse annoncée en cours de route : « la cascade n'a jamais planté ». Elle
n'avait pas planté pendant les 92 premières secondes.

**Règle.** Quand une panne apparaît en même temps qu'une nouveauté, le réflexe
est de l'imputer à la nouveauté. Construire d'abord le mode qui fait tourner le
matériel **sans** la nouveauté : c'est ce qui a tranché en une mesure. Et un
instrument qui survit au plantage vaut dix hypothèses — quand ça plante, plus
rien ne s'imprime, donc la trace série ne peut par construction rien dire.

---

## 15. Une boucle de calibration qui ne nourrit pas le chien de garde

**Symptôme.** Après une chute, la carte redémarre en boucle, toujours à
**5 719 ms d'uptime**, chaque fois précédée de « robot pas assez immobile, on
recommence ».

**Cause.** La calibration du gyro fait 300 lectures espacées de 3 ms, jusqu'à
quatre essais, sans jamais appeler `esp_task_wdt_reset()`. Un robot qui remue
fait échouer l'essai, et la boucle dépasse les 5 s du chien de garde.

**Règle.** Toute boucle d'initialisation qui peut recommencer doit nourrir le
chien de garde. Le symptôme — un uptime identique à la milliseconde près — est
la signature d'un chien de garde, jamais d'un aléa.

---

## 16. Le validateur devinait quel agent il validait

**Symptôme.** `12_valider_c.py` annonce 7,8 % d'écart relatif entre le C et
PyTorch, là où il donnait 2×10⁻⁷ la veille. Verdict : « ne pas téléverser ».

**Cause.** L'exporteur prend `--agent`, mais le validateur choisissait tout seul
le dernier jalon `agents/balancier_*_pas.zip`. On avait exporté
`balancier_final.zip`. Il comparait donc **le C d'un agent au Python d'un
autre**. Les deux codes étaient justes.

**Coût.** Un export déclaré mauvais alors qu'il était bon, et le téléversement
suspendu à tort.

**Règle.** Un outil de vérification ne doit **jamais deviner** ce qu'il
vérifie. `politique.h` portait déjà la réponse en ligne 5 ; il suffisait de la
lire. L'exporteur écrit désormais aussi `sortie_c/agent_source.txt`, et le
validateur lit l'un ou l'autre.

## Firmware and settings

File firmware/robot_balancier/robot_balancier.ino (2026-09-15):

/* =====================================================================
   ROBOT BALANCIER - ESP32 WROOM-32D + MPU6050 + 2x A4988 + NEMA17
   ---------------------------------------------------------------------
   ARCHITECTURE (changement principal vs version precedente)

     Boucle INTERNE  (200 Hz, cadencee par l INT du MPU)
         accel_roue [pas/s2] = Kp*err_angle + Ki*integ_angle + Kd*gyro
         vitesse_roue       += accel_roue * dt        <-- INTEGRATEUR
     Boucle EXTERNE  (40 Hz)
         angle_cible = angleOffset - ( Kp_v*err_vitesse + Ki_v*err_position )
     AUTO-TRIM (tres lent)
         recale angleOffset pour que la correction externe tende vers 0

   Pourquoi : pour un pendule inverse c est l ACCELERATION du chariot qui
   redresse le corps (theta'' = (g/L)*theta - a/L). Commander une vitesse
   proportionnelle a l angle ne peut pas stabiliser : la boucle fermee
   garde toujours un pole reel positif.

   Compatible core ESP32 Arduino 2.x ET 3.x (voir les macros TIMER_* plus bas)
   ===================================================================== */

#include <Wire.h>
#include <Preferences.h>
#include "soc/gpio_reg.h"
#include "esp_log.h"
#include "esp_task_wdt.h"

// ------------------------------------------ POLITIQUE APPRISE (agent RL)
// 1 634 poids en flash, deux couches de 32, activation tanh. Genere par
// 11_export_c.py et verifie contre PyTorch a 2e-7 pres par 12_valider_c.py.
// Elle remplace la boucle interne ET la boucle externe : elle a deja l ecart
// de position et la consigne de vitesse dans ses entrees.
// Mode d emploi complet : firmware/INTEGRATION.md.
#include "politique.h"

bool useAgent  = false;   // false = la cascade reglee a la main, true = l agent
bool testSigne = false;   // verification roues en l air, moteurs muets
unsigned long lastSigneMsg = 0;

// ---------------------------------------------- SECOUSSE (cmd '4')
// Reproduit l agitation de l agent -- inversions a pleine amplitude a 5 Hz --
// SANS l agent, SANS l IMU et SANS aucune boucle d asservissement. Si la carte
// plante aussi dans ce mode, la cause est le chemin moteur ; si elle tient,
// c est l agent ou sa lecture de l IMU. Une seule experience, deux hypotheses
// separees.
bool testSecousse = false;
unsigned long secousseT0 = 0;
int   secousseSigne = 1;
float SECOUSSE_AMP = 1400.0f;          // pas/s, l amplitude relevee sur l agent
unsigned long SECOUSSE_MS = 100;       // demi-periode -> 5 Hz, sa frequence minimale

// ------------------------------------- BOITE NOIRE, survit au redemarrage
// La RAM RTC n est pas effacee par un reset logiciel. On y ecrit l etape en
// cours a chaque phase de loop(). Apres un plantage, le demarrage la relit :
// on sait OU la boucle s est arretee, ce qu aucune trace serie ne peut dire
// puisque justement plus rien ne s imprime.
RTC_NOINIT_ATTR uint32_t rtcMagie;
RTC_NOINIT_ATTR uint32_t rtcEtape;
RTC_NOINIT_ATTR int32_t  rtcSps;
RTC_NOINIT_ATTR uint32_t rtcHalf;
// Marqueur propre a la tache IMU. Sans lui, un plantage residuel serait
// indiscernable : on saurait que loop() allait bien sans savoir ou en etait
// la lecture.
RTC_NOINIT_ATTR uint32_t rtcEtapeImu;
#define ETAPE_IMU(n) (rtcEtapeImu = (n))
static const char *nomEtapeImu(uint32_t e) {
  switch (e) {
    case 1: return "en attente du reveil";
    case 2: return "ecriture du registre 0x3D";
    case 3: return "requestFrom, lecture des 8 octets";
    case 4: return "extraction et publication";
    default: return "inconnue";
  }
}
#define RTC_MAGIE 0xBA1A0CE5u
#define ETAPE(n)  (rtcEtape = (n))
static const char *nomEtape(uint32_t e) {
  switch (e) {
    case  1: return "pollSerial";
    case  2: return "garde-fou IMU";
    case  3: return "transaction I2C";
    case  4: return "filtres et securites";
    case  5: return "boucle externe";
    case  6: return "boucle interne (politique comprise)";
    case  7: return "applyMotorSpeed";
    case  8: return "mode manuel";
    case  9: return "affinage du biais gyro";
    case 10: return "fin de deplacement minute";
    case 11: return "test de signe";
    case 12: return "secousse";
    case 13: return "sauvegarde des reglages";
    case 14: return "telemetrie";
    case 15: return "fin de boucle";
    case 16: return "surveillance du bus I2C";
    default: return "inconnue";
  }
}

// ------------------------------------------- COMPAT CORE ESP32 2.x / 3.x
// Le core 3.x a supprime timerAlarmWrite / timerAlarmEnable et change la
// signature de timerBegin. Ces macros donnent la meme API dans les 2 cas.
#if defined(ESP_ARDUINO_VERSION_MAJOR) && (ESP_ARDUINO_VERSION_MAJOR >= 3)
  #define TIMER_BEGIN_1MHZ()        timerBegin(1000000)
  #define TIMER_ATTACH(t, fn)       timerAttachInterrupt((t), (fn))
  #define TIMER_SET_PERIOD(t, us)   timerAlarm((t), (us), true, 0)
  #define TIMER_ENABLE(t)           ((void)0)
#else
  #define TIMER_BEGIN_1MHZ()        timerBegin(0, 80, true)
  #define TIMER_ATTACH(t, fn)       timerAttachInterrupt((t), (fn), true)
  #define TIMER_SET_PERIOD(t, us)   timerAlarmWrite((t), (us), true)
  #define TIMER_ENABLE(t)           timerAlarmEnable((t))
#endif

// ------------------------------------------------------------------ PINS
const int DIR_M1  = 5;
const int STEP_M1 = 18;
const int DIR_M2  = 17;
const int STEP_M2 = 16;
const int MPU_INT_PIN = 19;
const int I2C_SDA = 21;
const int I2C_SCL = 22;
const uint8_t MPU_ADDR = 0x68;

// Si un moteur est monte en miroir, passe son flag a true.
const bool INVERT_M1 = false;
const bool INVERT_M2 = false;

// 400 kHz s est revele trop rapide pour le cablage : NACK a repetition.
const uint32_t I2C_FREQ = 100000;

// --------------------------------------------------------- MECA / LIMITES
const int   STEPS_PER_REV = 1600;          // 200 * 1/8 de pas
float MAX_SPS        = 3000.0f;            // plafond vitesse roue  (cmd 'M')
const float MIN_SPS  = 6.0f;               // en dessous : moteur au repos
float MAX_ACCEL      = 25000.0f;           // saturation sortie PID interne (cmd 'R')
// Le couple d un pas-a-pas s effondre avec la vitesse. Si on demande la
// meme acceleration a 3000 pas/s qu a l arret, le moteur DECROCHE : il
// vibre sans tourner, le couple tombe a zero et le robot part au sol.
// A pleine vitesse on n autorise plus que (1 - ACCEL_DERATE) de l accel.
const float ACCEL_DERATE = 0.60f;
const float MAX_TILT_CORR = 6.0f;          // deg, autorite max boucle externe
const float MAX_POS_ERR   = 30000.0f;      // pas, saturation terme position
float MAX_LEAD            = 1600.0f;       // pas, avance max de la cible (cmd 'E')
const float FALL_LIMIT    = 30.0f;         // deg -> coupure
const float ARM_LIMIT     = 5.0f;          // deg -> autorise l armement

// ------------------------------------------------------------ FILTRAGE
const float TAU_COMP  = 1.0f;              // s, filtre complementaire
const float TAU_GYRO  = 0.012f;            // s, lissage du gyro pour le terme D
// Lissage de la vitesse dans la boucle externe (cmd 'L').
// A 0.15 s la coupure tombait a 1.06 Hz, soit exactement la frequence propre
// du pendule (mesuree a 1.35 Hz => centre de masse a ~13.6 cm de l axe).
// La boucle externe entretenait le mode propre au lieu de l ignorer.
// A 0.40 s la coupure descend a 0.40 Hz : elle laisse le pendule tranquille.
float TAU_SPEED = 0.40f;                   // s, lissage vitesse boucle externe
const int   OUTER_DIV = 5;                 // boucle externe = 200/5 = 40 Hz

// --------------------------------------------------------------- MOTEUR
hw_timer_t *motorTimer = NULL;
portMUX_TYPE timerMux = portMUX_INITIALIZER_UNLOCKED;

const uint32_t STEP_MASK   = (1UL << STEP_M1) | (1UL << STEP_M2);
const uint32_t STEP_MASK_D = (1UL << STEP_M1);
const uint32_t STEP_MASK_G = (1UL << STEP_M2);

// ===================================================== DEUX ROUES SEPAREES
// Ancienne version : un timer cadence a la demi-periode, les deux STEP sur le
// meme masque. Consequence, les deux roues recevaient rigoureusement les memes
// impulsions et le robot ne pouvait PAS tourner. C etait la limite ouverte
// depuis le debut du projet.
//
// Nouvelle version : le timer bat a cadence FIXE, et chaque moteur porte son
// propre accumulateur en virgule fixe 16.16. A chaque top on ajoute son
// increment ; quand l accumulateur deborde, ce moteur-la emet un pas. C est un
// Bresenham : deux vitesses independantes sur un seul timer, sans derive, et
// avec une erreur de phase bornee a un pas.
//
// Effet de bord bienvenu : la demi-periode ne se reprogramme plus jamais. On
// avait mesure 186 reprogrammations par seconde le 9 septembre en cherchant la
// cause d un plantage -- il n y en a plus aucune.
const uint32_t F_ISR         = 25000;               // Hz
const uint32_t ISR_PERIODE_US = 1000000UL / F_ISR;  // 40 us
// Un pas occupe un top pour monter et le suivant pour redescendre. En bornant
// l increment a la moitie de l echelle, on garantit au moins un top de repos
// entre deux pas, donc une impulsion propre de 40 us -- tres au-dessus du
// microseconde exigee par l A4988. Plafond : 12 500 pas/s par roue.
const uint32_t INCR_MAX      = 32768u;

volatile bool     motorRunning  = false;
volatile uint32_t accu[2]       = {0, 0};   // 16.16
volatile uint32_t incrPas[2]    = {0, 0};   // sps * 65536 / F_ISR
volatile int8_t   dirSigne[2]   = {1, 1};
volatile int32_t  pasFaits[2]   = {0, 0};   // odometrie, par roue
volatile uint32_t masqueImpulsion = 0;      // a faire retomber au top suivant
volatile uint32_t halfPeriod_us = ISR_PERIODE_US;   // conserve pour la trace

// HOMME MORT. L ISR compte ses propres declenchements ; la boucle de commande
// remet le compteur a zero a chaque mise a jour. Si la boucle se bloque, l ISR
// continue seule et le robot part a la derniere vitesse connue -- c est ce qu on
// voit sur les videos de panne. Passe ce seuil, l ISR s arrete d elle-meme.
// L ISR bat maintenant a 25 kHz quelle que soit la vitesse, et la commande est
// rafraichie 200 fois par seconde, soit 125 tops entre deux mises a jour.
// 1250 laisse un facteur 10, pour 50 ms de securite.
volatile uint32_t isrTicks = 0;
const uint32_t DEADMAN_TICKS = 1250;

// ------------------------------------------------------------- ETAT IMU
float pitch = 0.0f;
float gyroRate = 0.0f;                     // deg/s brut, axe X
float gyroFilt = 0.0f;                     // deg/s filtre, utilise par le terme D
float gyroX_offset = 0.0f;
unsigned long lastMeasureTime = 0;
unsigned long lastDisplayTime = 0;
volatile bool mpuDataReady = false;

// ------------------------------------------- ECHANTILLON IMU PARTAGE
// La lecture I2C vit maintenant dans sa propre tache, sur le coeur 0. Elle
// publie ici ; la boucle de commande, sur le coeur 1, consomme.
//
// Pourquoi : la boite noire du 9 septembre a montre quatre plantages sur
// quatre bloques dans la transaction I2C -- en secousse, en cascade et avec
// l agent, donc independamment de ce qui commande. Tant que la lecture etait
// dans loop(), la boucle de commande mourait avec elle et la carte redemarrait
// 5 s plus tard, robot par terre. Separee, elle survit et peut couper.
//
// La tache IMU n est VOLONTAIREMENT PAS abonnee au chien de garde de tache :
// si elle se bloque, elle ne doit pas faire redemarrer la carte. C est la
// boucle de commande qui constate le silence et desarme.
struct EchantillonImu {
  uint32_t seq;      // incremente a chaque publication : le consommateur compare
  uint32_t t_us;     // date de la transaction
  uint32_t d_us;     // sa duree
  int16_t  ay, az, gx;
  bool     ok;
};
static volatile EchantillonImu imuEch = {0, 0, 0, 0, 0, 0, false};
static portMUX_TYPE imuMux = portMUX_INITIALIZER_UNLOCKED;
static TaskHandle_t hTacheImu = NULL;
static uint32_t seqTraitee = 0;
uint32_t i2cBloc = 0;              // nombre de fois ou le bus s est fige
uint32_t silenceDepuis = 0;        // date du debut du silence, 0 si le bus va bien

// ==================================================== ENREGISTREUR 200 Hz
// La telemetrie sort a 10 Hz. C est assez pour surveiller, beaucoup trop lent
// pour identifier : la constante de temps du pendule inverse est predite a
// 132 ms, et l agent oscille au-dela de 5 Hz. On capture donc en RAM a la
// cadence de la boucle, puis on vide tranquillement sur le port serie.
//
// 1200 echantillons a 200 Hz = 6,0 s. Resolution spectrale 0,17 Hz, jusqu a
// 100 Hz. 33 ko sur les 304 ko libres.
#define ENR_N 1200
struct Echantillon {
  uint32_t t;        // us depuis le debut de la capture
  float    p;        // tangage brut, deg
  float    gf;       // gyro filtre, deg/s -- ce que voit la commande
  float    gb;       // gyro brut,   deg/s -- ce qu il faut pour le spectre
  float    s;        // vitesse commandee, pas/s
  float    inj;      // acceleration injectee, pas/s2 (0 hors balayage)
  float    pa;       // angle vu par l ACCELEROMETRE seul, deg
  float    mg;       // module de l acceleration, en g (1.000 au repos)
  int32_t  q;        // position, pas
  uint8_t  arme;     // 1 si la commande pilote, 0 si roues bloquees
};
static Echantillon enr[ENR_N];
static uint16_t enrN = 0;          // combien d echantillons ecrits
static bool     enrActif = false;
static bool     enrVidage = false;
static uint16_t enrVide = 0;       // ou en est le vidage
static uint32_t enrT0 = 0;
static const char *enrNom = "";
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
void loop() {
  uint32_t tLoop = micros();

  esp_task_wdt_reset();   // on signale au chien de garde qu on est vivant

  ETAPE(1);
  pollSerial();

  // Chien de garde IMU, deux etages.
  // 40 ms : on coupe la commande, l estimation d angle n est plus fraiche.
  ETAPE(2);
  if ((pidEnabled || testSecousse) && (micros() - lastMeasureTime) > 40000UL) {
    wheel_sps = 0;
    applyMotorSpeed(0);
  }
  // 150 ms : ce n est plus un hoquet, la tache I2C est bloquee dans le pilote.
  // On desarme TOUT et on le dit. Avant la separation des taches, ce cas ne
  // pouvait pas etre traite : la boucle etait bloquee elle aussi.
  if ((pidEnabled || testSecousse || useAgent)
      && (micros() - lastMeasureTime) > 150000UL) {
    pidEnabled = false; dualPid = false;
    useAgent = false; testSecousse = false; pendingArm = false;
    i2cBloc++;
    resetLoops();
    Serial.print(F(">>> SECURITE : bus I2C fige, tout desarme  (blocage n "));
    Serial.print(i2cBloc);
    Serial.println(F(")"));
    // On NE touche PAS a Wire depuis ici. La tache est peut-etre bloquee dans
    // le pilote en tenant son verrou : appeler Wire.end() depuis cette boucle
    // la bloquerait a son tour, et on aurait tout perdu. On observe.
    silenceDepuis = micros();
  }

  // Dernier recours. Si le capteur reste muet 3 s, la tache ne repartira plus
  // toute seule : on redemarre volontairement. Un redemarrage choisi vaut mieux
  // qu un chien de garde -- le message part, la boite noire reste lisible, et
  // la carte revient en 2,5 s au lieu de 7.
  ETAPE(16);
  if (silenceDepuis && (micros() - lastMeasureTime) > 3000000UL) {
    Serial.println(F(">>> BUS I2C MUET 3 s : redemarrage volontaire"));
    Serial.flush();
    delay(20);
    ESP.restart();
  }
  if (silenceDepuis && (micros() - lastMeasureTime) < 100000UL) {
    Serial.print(F(">>> bus I2C reparti tout seul apres "));
    Serial.print((micros() - silenceDepuis) / 1000);
    Serial.println(F(" ms"));
    silenceDepuis = 0;
  }

  // ---------------------------------------- CONSOMMATION DE L ECHANTILLON
  // Plus aucune transaction I2C ici : on lit ce que la tache a publie. Si elle
  // est figee, seq n avance plus, ce bloc ne s execute pas, et le garde-fou de
  // silence plus bas desarme proprement au lieu de laisser le chien de garde
  // redemarrer la carte.
  ETAPE(3);
  uint32_t seq; int16_t rawAY, rawAZ, rawGX; bool dataOk; uint32_t tEch, dI2c;
  portENTER_CRITICAL(&imuMux);
  seq    = imuEch.seq;
  rawAY  = imuEch.ay;  rawAZ = imuEch.az;  rawGX = imuEch.gx;
  dataOk = imuEch.ok;
  tEch   = imuEch.t_us;
  dI2c   = imuEch.d_us;
  portEXIT_CRITICAL(&imuMux);

  if (seq != seqTraitee) {
    seqTraitee = seq;

    unsigned long now = tEch;
    float dt = (now - lastMeasureTime) * 1e-6f;
    lastMeasureTime = now;
    if (dt < 0.001f || dt > 0.05f) dt = 0.005f;
    loopHz += (1.0f / dt - loopHz) * 0.02f;

    if (dI2c > maxI2cUs) maxI2cUs = dI2c;

    if (dataOk) {
      i2cReadOK++;
      i2cFailStreak = 0;

      float ay = rawAY, az = rawAZ;
      float magG = sqrtf(ay * ay + az * az) / 16384.0f;
      bool accOk = (magG > 0.6f && magG < 1.4f);

      gyroRate = ((float)rawGX / 131.0f) - gyroX_offset;

      float gyroPitch = pitch + gyroRate * dt;
      if (accOk) {
        float accPitch = atan2f(ay, az) * 180.0f / PI;
        while (accPitch - gyroPitch >  180.0f) accPitch -= 360.0f;
        while (accPitch - gyroPitch < -180.0f) accPitch += 360.0f;
        float alpha = TAU_COMP / (TAU_COMP + dt);
        pitch = alpha * gyroPitch + (1.0f - alpha) * accPitch;
      } else {
        pitch = gyroPitch;
      }
    } else {
      // Echantillon manque : on NE coupe PAS les moteurs. On propage
      // l estimation avec le dernier gyro connu. Couper la commande a
      // chaque hoquet I2C (2,3 fois par seconde) desequilibrait le robot
      // bien plus que l erreur d estimation d un echantillon a 5 ms.
      i2cReadFail++;
      if (i2cFailStreak < 255) i2cFailStreak++;
      pitch += gyroRate * dt;
      if (i2cFailStreak == 20) i2cBusRecover();
    }

    // ---- capture, a la cadence de la boucle
    if (enrActif && enrN < ENR_N) {
      Echantillon &e = enr[enrN];
      e.t  = micros() - enrT0;
      e.p  = pitch - angleOffset;
      e.gf = gyroFilt;
      e.gb = gyroRate;
      e.s   = wheel_sps;
      e.inj = injCourant;
      // L accelerometre brut n avait jamais ete enregistre. Sans lui,
      // bruit_accel reste SUPPOSE dans modele.py -- c est le dernier
      // parametre de bruit qu on ne mesure pas.
      e.pa  = atan2f((float)rawAY, (float)rawAZ) * 180.0f / PI;
      e.mg  = sqrtf((float)rawAY*(float)rawAY + (float)rawAZ*(float)rawAZ) / 16384.0f;
      e.q    = pasMoyens();
      // 0 = roues figees, 3 = poussee imposee, 1 = cascade, 2 = desarme
      e.arme = (uint8_t)(lacherActif ? 0 : (pousseeActive ? 3 : (pidEnabled ? 1 : 2)));
      enrN++;
      if (enrN >= ENR_N) { enrActif = false; enrVidage = true; }
    }

    // Lissage dedie au terme D : sans lui les vibrations des pas-a-pas
    // dominent completement la sortie (cf. sps qui sautait a +/-500 alors
    // que l erreur d angle etait a 0.03 deg).
    gyroFilt += (gyroRate - gyroFilt) * (dt / (TAU_GYRO + dt));

    // Panne franche du capteur : la, on coupe.
    ETAPE(4);
    if (i2cFailStreak >= 10) {
      if (pidEnabled) {
        pidEnabled = false; dualPid = false;
        resetLoops();
        Serial.println(F(">>> SECURITE : MPU muet, PID coupe"));
      }
    } else if (pidEnabled) {
      if (fabsf(pitch - angleOffset) > FALL_LIMIT) {
        pidEnabled = false; dualPid = false;
        pendingArm = autoRearm;
        resetLoops();
        Serial.println(F(">>> SECURITE : angle hors limite, PID coupe"));
      } else if (satSince != 0 && (millis() - satSince) > SAT_MAX_MS) {
        pidEnabled = false; dualPid = false;
        pendingArm = autoRearm;
        satSince = 0;
        resetLoops();
        Serial.println(F(">>> SECURITE : vitesse saturee trop longtemps (roues dans le vide ?)"));
      } else {
        // L agent fait deja le travail de la boucle externe. Et surtout,
        // l auto-trim qu elle contient deplacerait angleOffset, c est-a-dire
        // la reference de verticale que l agent lit -- elle bougerait sous
        // ses pieds pendant qu il travaille.
        if (dualPid && !useAgent) {
          if (++outerCounter >= OUTER_DIV) {
            outerCounter = 0;
            ETAPE(5);
            outerLoop(dt * OUTER_DIV);
          }
        } else {
          target_angle = angleOffset;
          speed_angle_corr = 0.0f;
        }
        ETAPE(6);
        innerLoop(dt);
      }
    } else if (manualMode) {
      ETAPE(8);
      float d = MANUAL_ACCEL * dt;
      float e = manual_target_sps - wheel_sps;
      if (e >  d) e =  d;
      if (e < -d) e = -d;
      wheel_sps += e;
      applyMotorSpeed(wheel_sps);
    }

    // Tant que le robot est desarme et vraiment immobile, on affine le biais
    // du gyro. Le critere est la DISPERSION, pas la valeur : un biais faux de
    // 9 deg/s donne une lecture eloignee de zero mais tres stable.
    ETAPE(9);
    if (!pidEnabled && !manualMode && dataOk) {
      gyroBiasMean += (gyroRate - gyroBiasMean) * 0.01f;
      gyroBiasDev  += (fabsf(gyroRate - gyroBiasMean) - gyroBiasDev) * 0.01f;
      if (gyroBiasDev < 0.8f) gyroX_offset += gyroBiasMean * 0.002f;
    } else {
      gyroBiasMean = 0.0f;
      gyroBiasDev  = 10.0f;
    }
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

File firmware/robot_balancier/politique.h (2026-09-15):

/* =====================================================================
   POLITIQUE APPRISE PAR RENFORCEMENT -- GENERE PAR 11_export_c.py
   NE PAS EDITER A LA MAIN.

   agent    : agents/balancier_final.zip
   reseau   : 15 -> 32 -> 32 -> 2,  activation tanh,  1634 poids
   flash    : 6536 octets de constantes
   cadence  : la politique decide a 100 Hz, l integrateur reste a 200 Hz

   ---------------------------------------------------------------------
   USAGE, dans robot_balancier.ino

     #include "politique.h"

     // dans resetLoops() :
         politique_reset();

     // dans innerLoop(), a la place du calcul de accel :
         static bool tickPol = false;
         static float accelPol = 0.0f;
         tickPol = !tickPol;
         if (tickPol) {                       // 100 Hz : un tick sur deux
           accelPol = politique_accel(pitch - angleOffset, gyroFilt,
                                      wheel_sps, stepCount, target_speed_sps,
                                      millis());
           if (politique_defaut != POL_OK) { ... voir INTEGRATION.md }
         }
         float accel = accelPol;

   Le reste de innerLoop() ne change pas : la limite d acceleration deratee,
   l integration, l anti-emballement et applyMotorSpeed() restent en place.

   ---------------------------------------------------------------------
   CONVENTIONS -- a verifier sur la carte AVANT de le laisser debout

     angle   pitch - angleOffset, en DEGRES, positif = penche vers l AVANT
     gyro    gyroFilt, en deg/s, meme signe que la derivee de l angle
     sps     wheel_sps, la vitesse commandee en pas/s
     pas     stepCount, l odometrie en pas
     cible   target_speed_sps, la consigne de vitesse en pas/s

   Le signe de l angle est le point critique du transfert : s il est
   inverse, le robot part par terre en une demi-seconde. Le protocole de
   verification est dans firmware/INTEGRATION.md.
   ===================================================================== */

#ifndef POLITIQUE_H
#define POLITIQUE_H

#include <math.h>

#define POL_N_OBS   15
#define POL_N_CACHE 32
#define POL_N_ACT    2

/* --- grandeurs physiques, doivent correspondre a modele.py ------------- */
#define POL_RAD_PAR_PAS  (2.0f * 3.14159265358979f / 1600.0f)
#define POL_RAYON_ROUE   0.032500f        /* m */
#define POL_MAX_ACCEL    25000.0f     /* pas/s2, pleine echelle de l action */
#define POL_V_MAX        0.1500f         /* m/s, pleine echelle de la consigne */
#define POL_DT_POL       0.01f               /* s, periode de la politique */

/* --- garde-fous, tous CHIFFRES en simulation -------------------------------
   POL_ANGLE_MAX  au-dela de 11 deg l agent ne se rattrape plus JAMAIS
                  (mesure : 6/6 rattrapes a 10 deg, 0/6 a 12 deg, laches
                  immobiles). Ton FALL_LIMIT de 30 deg le laisse donc
                  s acharner 19 deg apres que c est perdu. Ici on coupe tot.
   POL_SAT_MS     en marche normale l action ne sature JAMAIS : 0,0 % du temps
                  a |a| > 0,98, meme tres perturbe. Une saturation qui dure
                  est donc une anomalie franche, sans faux positif.
   Le test NaN    n est pas une precaution de principe : aucune comparaison
                  avec NaN n etant vraie, un NaN traverse EN SILENCE le
                  "if (a < MIN_SPS)" et le "if (a > lim)" de applyMotorSpeed,
                  et (uint32_t)(500000.0f/NaN) finit borne a 20 us de
                  demi-periode -- les moteurs partent a 25 000 pas/s.       */
#define POL_ANGLE_MAX    14.0f   /* deg, marge sur les 11 mesures */
#define POL_SAT_MS         120   /* ms de saturation continue tolerees */
#define POL_SAT_SEUIL    0.98f

enum {
  POL_OK = 0,
  POL_DEFAUT_ANGLE,      /* hors du domaine ou il sait se rattraper */
  POL_DEFAUT_SATURE,     /* commande collee a la butee trop longtemps */
  POL_DEFAUT_NAN         /* sortie non numerique */
};
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

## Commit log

2026-09-15 Robot balancier : mécanique, firmware et simulation réunis
    Fusion des dossiers « robot balancier » (firmware, outils, carnet) et
    « mujoco » (simulation, PPO, export C) en un seul dépôt.
    - hardware : CAO SolidWorks et STL du 25 août 2026, nomenclature,
    câblage, montage réel (IMU déplacée loin des moteurs)
    - firmware : double PID et agent appris dans le même croquis
    - tools : moniteur série et pupitre de pilotage
    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
    [Assemblage1 - nema17HS3401S-1.STL, Assemblage1 - nema17HS3401S-2.STL, Assemblage1 - piece1-1.STL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]
2026-09-15 Préciser le rôle du double PID
    Réglé à la main pour mettre en pratique les cours d'automatique, par
    essais et mesures. La démarche complète (modèle du pendule, pôles,
    correcteur dimensionné) a été volontairement sautée pour passer
    directement à l'apprentissage par renforcement.
2026-09-15 README en anglais par défaut, version française à part
    README.md en anglais, affiché par GitHub, et README.fr.md en français,
    reliés par un lien en tête. « Double PID » partout, et correction :
    la référence du 9 septembre datait de la même soirée, pas de la veille.
2026-09-15 Tous les README en anglais et en français, projet renommé
    - hardware, firmware, simulation, donnees : README.md en anglais,
    README.fr.md en français ; câblage en wiring.md et cablage.md
    - titre « Robot pendule inversé », gardé en français
    - emplacement du modèle du robot (MJCF, pas d'URDF) dans les README
    - « double PID » partout dans les versions françaises
2026-09-15 Batteries : déchargées, pas d'élément mort
    Le 9 septembre, les batteries étaient déchargées ; rechargées, tout est
    revenu. Retiré « refaire le pack » des points ouverts, remplacé la ligne
    tension batterie par un conseil de charge, correction datée dans ETAT.md.
2026-09-15 Audit : commentaires et faits périmés corrigés
    - CLAUDE.md : résonance mesurée à 71 Hz (plus 113), poussées sur le
    moteur fidèle, plafond MAX_SPS actuel
    - modele.py et balancier.xml : le robot tourne depuis le 10 septembre,
    plus de « un seul timer »
    - INTEGRATION.md : chemin d'export, direction appliquée après la politique
    - 11_export_c.py et politique.h : commentaires seuls (réexporté, validé
    à 3e-7, firmware 364 483 octets inchangé)
    - README : le carnet est daté du 28 août
    [politique.h]
